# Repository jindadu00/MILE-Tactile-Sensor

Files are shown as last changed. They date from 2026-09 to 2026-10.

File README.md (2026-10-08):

# MILE Fingertip Visuotactile Sensor

CAD files, material references, fabrication instructions, and LED-control firmware for the fingertip visuotactile sensor used in **MILE: A Mechanically Isomorphic Hand Exoskeleton and Visuotactile Robotic Hand for Data Collection in Dexterous Manipulation**.

[MILE project page](https://sites.google.com/view/mile-system) · [Bill of materials](BOM/BOM.xlsx)

## Sensor overview

The module combines a compliant silicone sensing layer, a reflective coating, a transparent acrylic support, internal LED illumination with an ATtiny85-based controller, a miniature RGB camera with a **120° fixed-focus lens**, and printed structural parts. The documented assembly uses **eight LEDs** for red, green, and blue illumination from three directions. The supplied firmware defines **ten color positions** in the order `RRRBBGGGBB`, with the final two blue LEDs optional.

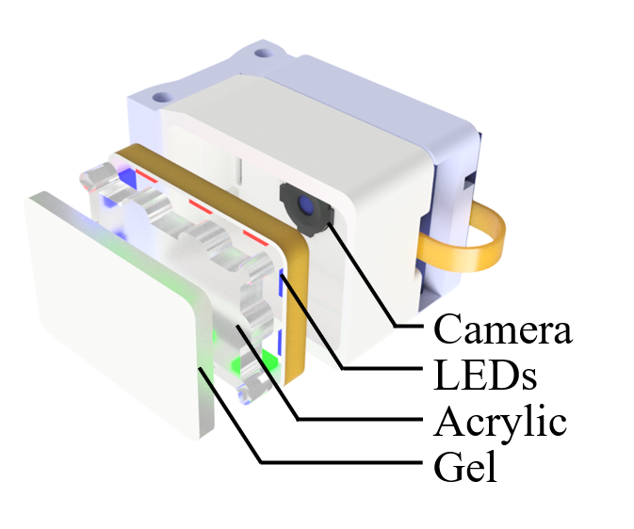
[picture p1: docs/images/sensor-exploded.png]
Exploded view of the sensor, showing the camera, LEDs, acrylic support, and gel layer.


*Sensor exploded view corresponding to Fig. 3(d) of the MILE manuscript.*

## Released files

| File | Description |
| --- | --- |
| [assembly.STEP](CAD/STEP/assembly.STEP) | Sensor assembly |
| [baseCamera.STEP](CAD/STEP/baseCamera.STEP) | Camera-side structural component |
| [baseConnector.STEP](CAD/STEP/baseConnector.STEP) | Connecting structural component |
| [acrylic.STEP](CAD/STEP/acrylic.STEP) | Geometry of the 3 mm transparent acrylic support |
| [acrylic.DXF](CAD/DXF/acrylic.DXF) | Laser-cutting outline for the 3 mm acrylic support |
| [camera.STEP](CAD/STEP/camera.STEP) | Camera geometry reference |
| [GelMode.STEP](CAD/STEP/GelMode.STEP) | Silicone casting mold, printed in PLA |
| [BOM.xlsx](BOM/BOM.xlsx) | Components, consumables, and supplier references |
| [Illumination assembly and wiring](docs/led-wiring.md) | Assembly reference photographs and soldering instructions |
| [MILE_LED.ino](Firmware/MILE_LED/MILE_LED.ino) | ATtiny85 LED-control sketch with the `RRRBBGGGBB` color sequence |
| [Firmware setup](Firmware/README.md) | Upload instructions, pin settings, and brightness configuration |

This release covers mechanical designs, material references, fabrication, hardware assembly, and LED-control firmware.

## Materials and supplier references

Silicone, coatings, adhesives, wires, and printing materials are shared consumables. Links were supplied by the authors; confirm product options before purchase.

| **Component or material** | **Specification / role** | **Supplier reference** |
| --- | --- | --- |
| Silicone elastomer | Smooth-On Solaris; MILE recipe: A:B = **1:2 by mass** | [Listing](https://e.tb.cn/h.8CfLBqZ0Gq6BevB?tk=VI4yTMjDRcV) |
| Mold release agent | Coat the internal casting surfaces | [Listing](https://item.taobao.com/item.htm?id=39270711126) |
| Transparent silicone adhesive | Bond the uncoated gel surface to acrylic | [Listing](https://item.taobao.com/item.htm?id=593987256695) |
| White thermally conductive adhesive | Fix the camera after focusing | [Listing](https://item.taobao.com/item.htm?id=600594258578) |
| Gray silicone coating ink | Request custom **coolgray** | [Listing](https://item.taobao.com/item.htm?id=594951473152) |
| Coating thinner | Compatible thinner from the coating supplier | [Listing](https://item.taobao.com/item.htm?id=594951473152) |
| LED strip | 2.6 mm wide; **8 LEDs in the documented assembly**; firmware defines 10 color positions with the final 2 blue LEDs optional | [Listing](https://item.taobao.com/item.htm?id=570411659913) |
| LED controller | ATtiny85-based controller board | [Listing](https://detail.tmall.com/item.htm?id=654071116354) |
| Camera | **120° fixed-focus module with small board** | [Listing](https://item.taobao.com/item.htm?id=713113178023) |
| 3D printing filament | Bambu PLA Basic| [Listing](https://e.tb.cn/h.8yFoHAKwVr1shmb?tk=97oXTMkPX9c) |

Additional procurement references for C-0030 silicone, silver ink, marker ink, and spray-gun cleaner are retained in `Sheet2` of the spreadsheet. They are not required additions to the recipe below.

## Fabrication and assembly

### 1. Prepare the mold and parts

1. Print [GelMode.STEP](CAD/STEP/GelMode.STEP) in PLA to make the silicone casting mold.
2. Temporarily seal the mold's open bottom with a flat acrylic plate to prevent leakage during casting and curing. The open-bottom design facilitates removal of the cured silicone layer. This sealing plate is separate from the sensor's acrylic support.
3. Apply mold release agent to the internal casting surfaces, following the release agent's instructions.
4. Print `baseCamera` and `baseConnector` in PLA.
5. Cut the sensor support from **3 mm transparent acrylic** using [acrylic.DXF](CAD/DXF/acrylic.DXF). Import the drawing in millimeters without scaling.

### 2. Mix, degas, and cast the silicone

1. Weigh Solaris A and B at **A:B = 1:2 by mass**. For example, combine 10 g of A with 20 g of B.
2. Mix thoroughly with a mixer or manually with a spoon/spatula, incorporating the material along the container walls and bottom.
3. Degas in a vacuum chamber until bubbles introduced during mixing are removed. Leave space for the mixture to expand during degassing.
4. Pour the degassed mixture into the prepared mold, minimizing new bubbles.
5. Leave the filled mold in a **45°C temperature-controlled chamber for 24 h**, following the authors' laboratory fabrication procedure.
6. Demold the transparent silicone layer and check the optical region for bubbles and defects.

**Formulation selection:** Section III-C of the manuscript specifies A:B = 1:2 by mass. Supplementary Section IV-B describes screening ten ratios using compression force-displacement responses and qualitative observations of clarity, recovery, tackiness, and fabrication stability. The selected formulation is a practical compromise for this sensor, rather than a universal optimum.

The [manufacturer's technical bulletin](https://www.smooth-on.com/tb/files/Solaris_TB.pdf) specifies a standard 1:1 formulation. The **1:2 formulation above is the experimentally selected MILE recipe**. The 45°C / 24 h schedule is the laboratory procedure supplied by the authors.

### 3. Apply the reflective coating

1. Weigh gray ink stock and its compatible thinner at **ink:thinner = 1:3 by mass**.
2. Add the curing agent supplied with the ink at the supplier's specified dose, mix thoroughly, then use a spray gun to deposit a thin, uniform film on the contact-facing silicone surface. The curing-agent dose is separate from the ink-to-thinner ratio.
3. Make the coating uniform and opaque. Avoid excessive thickness, which can reduce sensing sensitivity according to the authors' fabrication observations.
4. Allow the coating to dry for approximately **8 h at room temperature**, or accelerate drying with a heat gun. Ensure that the coating is fully dry before assembly.

Leave the opposite gel surface uncoated for bonding to acrylic.

### 4. Assemble illumination, acrylic, and gel

1. Assemble the acrylic support and LED strip according to the exploded view and assembly CAD. The documented assembly uses **eight LEDs**, corresponding to the first eight positions of the firmware sequence `RRRBBGGGBB`. The final two blue LEDs can be omitted from the end of the signal chain. Secure the support in the middle of the sensor structure.
2. Route and solder the LED wires: **red for 5 V**, **black for ground**, and **blue for the control signal**. The camera board supplies shared 5 V and ground to the ATtiny85 board. Upload the [LED-control sketch](Firmware/MILE_LED/MILE_LED.ino) using the [firmware setup instructions](Firmware/README.md), then check the color order and illumination before bonding the gel. See [assembly photographs and soldering instructions](docs/led-wiring.md).
3. Use transparent silicone adhesive to bond the **uncoated side** of the gel to acrylic. Avoid trapped air in the optical interface.
4. Allow approximately **8 h at room temperature** for the bond to cure, following the authors' procedure for the selected adhesive. Check the bond before continuing.

### 5. Install and focus the camera

1. After the gel-to-acrylic bond has cured, insert the camera into the structure's viewing opening.
2. With illumination on and the camera image displayed, adjust focus for the clearest view of the sensing surface at the assembled distance.
3. Fix the camera with thermally conductive adhesive. Keep adhesive away from the lens and optical path, and preserve the focused camera pose during fixation.
4. After fixation, check illumination coverage, image focus, and visible image changes under gentle contact.

## Maintenance

The modular construction allows the gel and camera to be replaced separately. Replace a damaged gel while retaining the camera, or replace and refocus a damaged camera while retaining the gel. During removal, protect the illumination assembly and the gel or camera being retained. The acrylic support can be replaced as needed.

## Citation

Please cite the associated [MILE arXiv preprint](https://arxiv.org/abs/2512.00324). A downloadable BibTeX entry is provided in [citation.bib](citation.bib).

```bibtex
@misc{du2025milemechanicallyisomorphicexoskeleton,
  title         = {MILE: A Mechanically Isomorphic Hand Exoskeleton and Visuotactile Robotic Hand for Data Collection in Dexterous Manipulation},
  author        = {Jinda Du and Jieji Ren and Qiaojun Yu and Ningbin Zhang and
                   Yu Deng and Xingyu Wei and Yufei Liu and Guoying Gu and
                   Xiangyang Zhu},
  year          = {2025},
  eprint        = {2512.00324},
  archivePrefix = {arXiv},
  primaryClass  = {cs.RO},
  url           = {https://arxiv.org/abs/2512.00324}
}
```

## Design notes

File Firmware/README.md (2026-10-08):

# LED-control firmware

[MILE_LED/MILE_LED.ino](MILE_LED/MILE_LED.ino) provides constant RGB illumination using an ATtiny85 board and the [Adafruit NeoPixel library](https://github.com/adafruit/Adafruit_NeoPixel).

## Configuration

| Setting | Default | Description |
| --- | --- | --- |
| `LED_PIN` | `3` | Arduino digital-pin number; P3 / PB3 on the pictured ATtiny85 board |
| `LED_PATTERN` | `"RRRBBGGGBB"` | Color order from the signal-input end of the LED strip |
| `NUMPIXELS` | `10` | Calculated from the pattern length |
| `RED_LEVEL` | `15` | Red channel setting, 0–255 |
| `GREEN_LEVEL` | `15` | Green channel setting, 0–255 |
| `BLUE_LEVEL` | `15` | Blue channel setting, 0–255 |
| Pixel format | `NEO_GRB + NEO_KHZ800` | GRB byte order and 800 kHz signaling, retained from the supplied sketch |

The first eight color positions are `RRRBBGGG`. If the last two blue LEDs are omitted from the physical strip, the same sketch still supplies the correct colors to those first eight LEDs. This applies when LEDs are omitted from the **end of the signal chain**; omitting LEDs at its beginning or middle requires adjusting the pattern.

The brightness defaults are adjustable starting values, not recovered experimental calibration. Tune them with the assembled gel and camera at the intended exposure, checking for clipping and uneven illumination. The optional final two LEDs change the illumination distribution when fitted.

## Upload and check

1. Install Arduino IDE and the board package appropriate for the ATtiny85 controller. Select the actual board and CPU clock configuration. For board support, consult the [ATTinyCore documentation](https://github.com/SpenceKonde/ATTinyCore).
2. Install **Adafruit NeoPixel** through the Arduino Library Manager.
3. Open `MILE_LED/MILE_LED.ino`. Keep the sketch inside the folder named `MILE_LED`.
4. Match `LED_PIN` to the blue signal wire's board terminal. The supplied assembly uses P3 / PB3. Check the strip's input direction and pixel format.
5. Compile and upload using the selected board's supported upload method. On [Digispark-style boards](https://github.com/ArminJo/DigistumpArduino#pin-layout), P3 also carries USB data; disconnect the LED signal wire during USB programming and reconnect it afterward. Restore the [shared camera-board 5 V and ground connections](../docs/led-wiring.md) for operation.
6. Verify the color order before final assembly. Temporarily setting `LED_PATTERN` to `"R......."` lights only index 0 on an eight-position strip. `"G......."` and `"B......."` allow checking the other color channels; restore `"RRRBBGGGBB"` afterward.
7. Adjust `RED_LEVEL`, `GREEN_LEVEL`, and `BLUE_LEVEL` as needed, then check the assembled camera image.

The sketch sets all pixel colors in `setup()` and transmits one frame. `loop()` is empty because the LEDs retain the last transmitted colors for constant illumination.

## License

The sketch is adapted from the NeoPixel Ring simple example by Shae Erisson (2013) and retains its GPLv3 license notice. [MILE_LED/LICENSE.txt](MILE_LED/LICENSE.txt) contains the license text for this sketch.

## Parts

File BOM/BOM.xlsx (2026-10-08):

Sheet: Sheet1
Component | Specification | Purchase Link
Silicone elastomer | Solaris; A:B = 1:2 by mass (MILE manuscript III-C) | https://e.tb.cn/h.8CfLBqZ0Gq6BevB?tk=VI4yTMjDRcV
Silicone adhesive | Transparent silicone adhesive; gel-to-acrylic bond | https://item.taobao.com/item.htm?id=593987256695
Miniature camera module | 120° fixed-focus module with small board | https://item.taobao.com/item.htm?id=713113178023
Microcontroller board | ATtiny85-based LED controller board | https://detail.tmall.com/item.htm?id=654071116354
LEDs (strip segment) | 2.6 mm RGB strip; 8 LEDs in assembly; 10 firmware positions, final 2 blue optional | https://item.taobao.com/item.htm?id=570411659913
3D printing filament | Bambu PLA Basic; for the silicone casting mold and sensor structural parts | https://e.tb.cn/h.8yFoHAKwVr1shmb?tk=97oXTMkPX9c
Mold release agent | Apply to internal surfaces of gel casting mold | https://item.taobao.com/item.htm?id=39270711126
Gray silicone coating ink | Custom coolgray; dry at room temperature ~8 h; a heat gun can accelerate drying | https://item.taobao.com/item.htm?id=594951473152
Coating thinner | Compatible thinner; ink:thinner = 1:3 by mass | https://item.taobao.com/item.htm?id=594951473152
Thermally conductive adhesive | White adhesive; fix camera after focus adjustment | https://item.taobao.com/item.htm?id=600594258578

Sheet: Sheet2
Reference item | Specification / use | Purchase Link | Selection note
C-0030 silicone | Supplier notes: A 250 g + B 250 g | https://item.taobao.com/item.htm?id=668500306966 | Reference only; not Solaris recipe
Spray-gun cleaner | T-03 cleaner | https://item.taobao.com/item.htm?id=827040574354 | Equipment cleaning consumable
Marker ink | Black fluorescent tactile marker ink | https://item.taobao.com/item.htm?id=599683958497 | Reference only; not in described recipe
Silver ink | Silver coating ink | https://item.taobao.com/item.htm?id=601283906543 | Reference only; gray ink used in described recipe

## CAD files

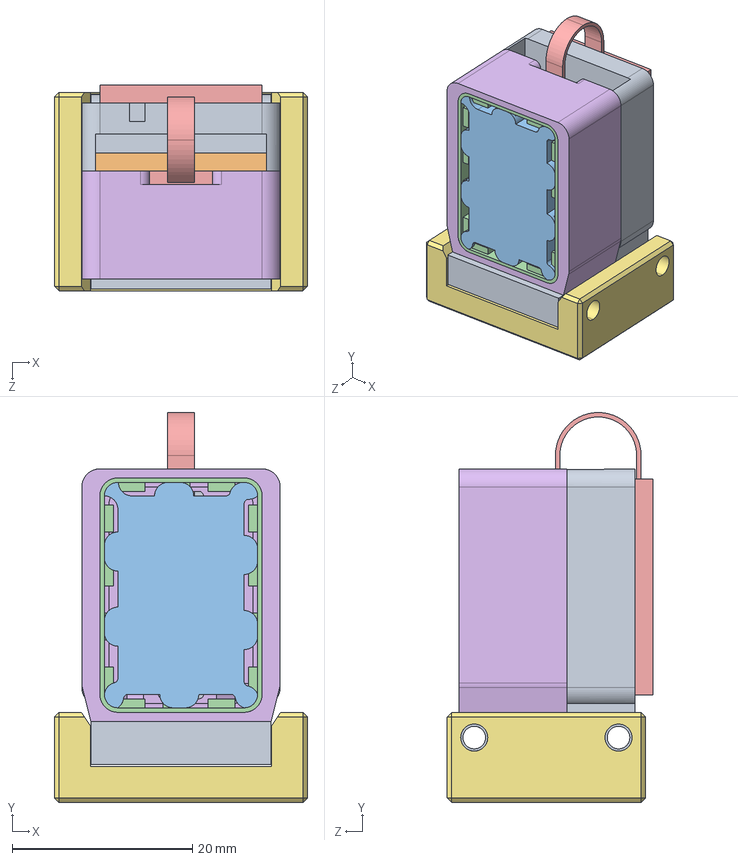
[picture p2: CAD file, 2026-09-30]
CAD/STEP/assembly.STEP
28.1 x 43.3 x 22.8 mm
baseConnector_v0.2
ATtiny
acrylic
LED
microCamera
base
fingertipConnector

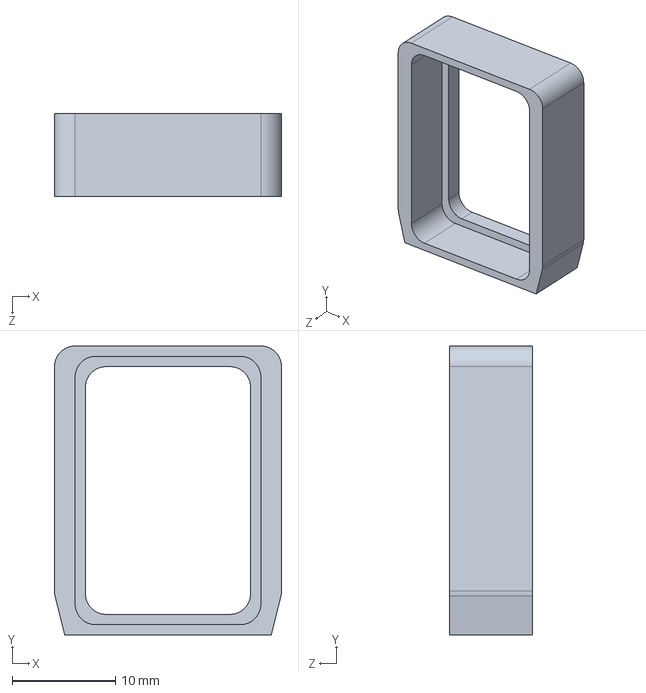
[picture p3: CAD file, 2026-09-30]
CAD/STEP/GelMode.STEP
22.0 x 28.0 x 8.00 mm

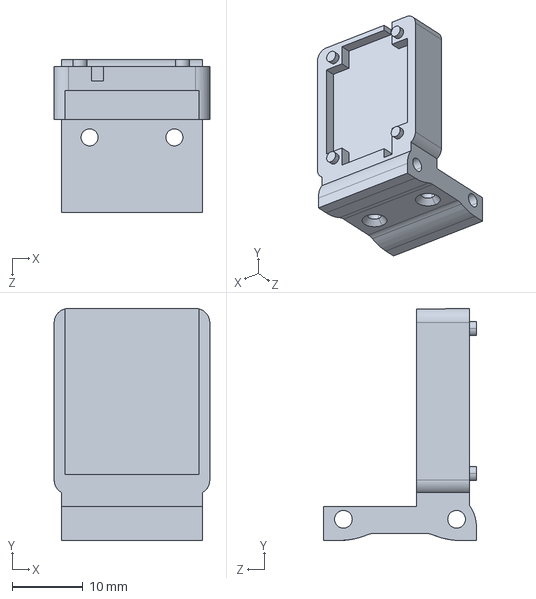
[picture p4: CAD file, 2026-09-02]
CAD/STEP/baseConnector.STEP
22.0 x 32.8 x 21.6 mm

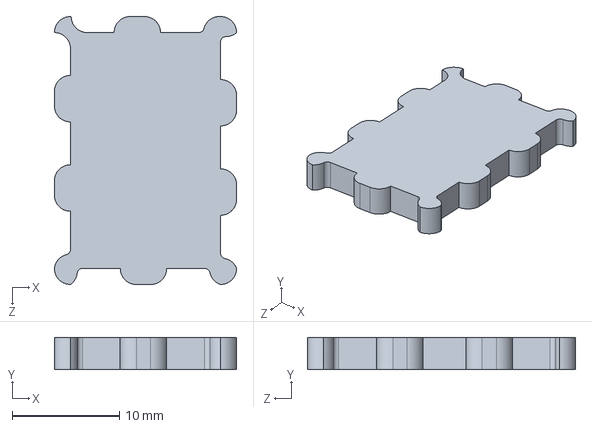
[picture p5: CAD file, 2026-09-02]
CAD/STEP/acrylic.STEP
17.0 x 3.00 x 25.0 mm

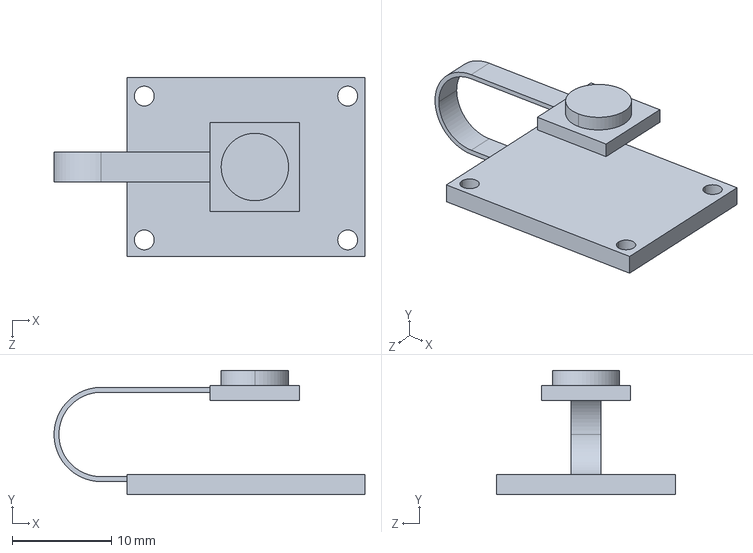
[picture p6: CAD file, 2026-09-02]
CAD/STEP/camera.STEP
31.4 x 12.5 x 18.0 mm

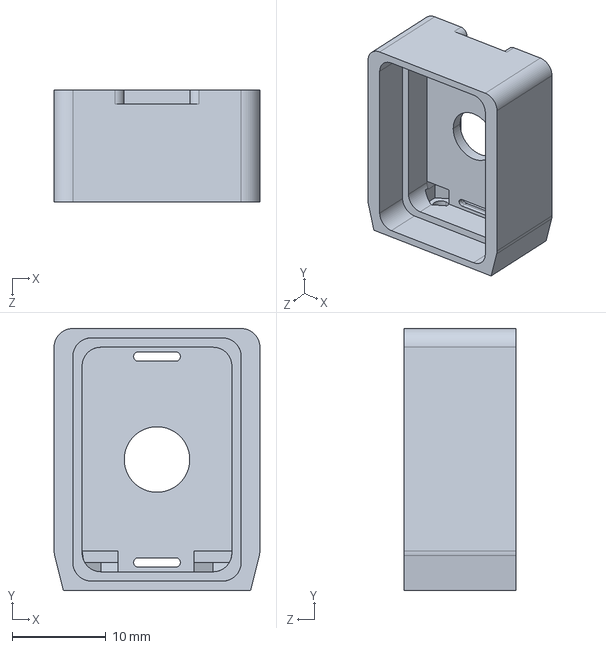
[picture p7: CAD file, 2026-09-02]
CAD/STEP/baseCamera.STEP
22.0 x 28.0 x 12.0 mm

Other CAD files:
CAD/DXF/acrylic.DXF

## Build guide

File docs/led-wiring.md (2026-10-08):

# Illumination assembly and wiring

The photographs below show the sensor's LED strip seated inside the printed housing, the ATtiny85 controller board, and the camera board. The documented assembly uses **eight LEDs** for red, green, and blue illumination from three directions. The released firmware defines ten color positions, `RRRBBGGGBB`, with the final two blue LEDs optional. The camera uses a **120° fixed-focus lens**. The camera board provides a shared **5 V supply**, and the ATtiny85 board controls the LED strip.

## Assembly photographs

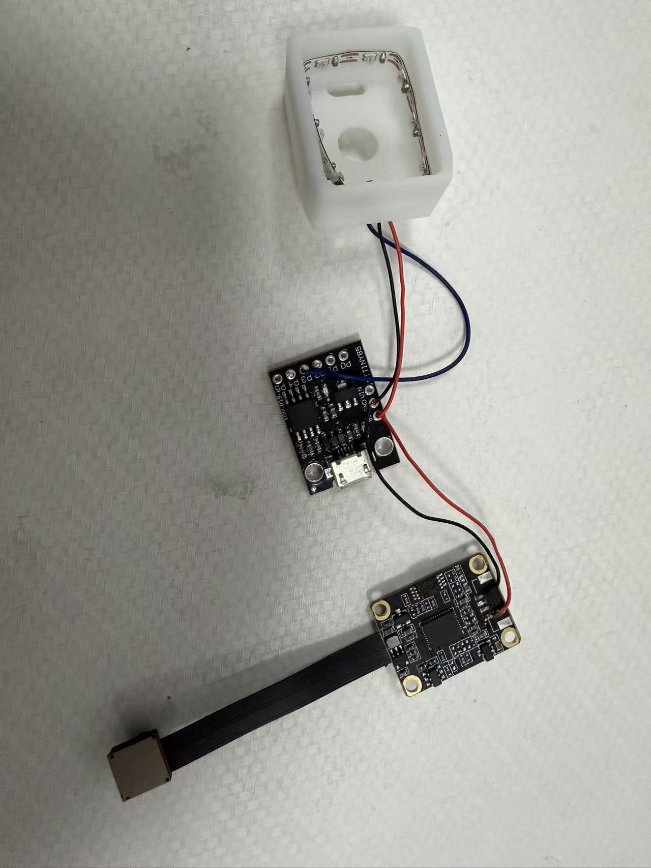
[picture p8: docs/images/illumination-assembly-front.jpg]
LED strip inside the sensor housing, controller board front, and camera board connected by wires.


*Front view of the illumination assembly and connected boards. The LED strip follows the inner perimeter of the housing, and the wires leave through the housing opening.*

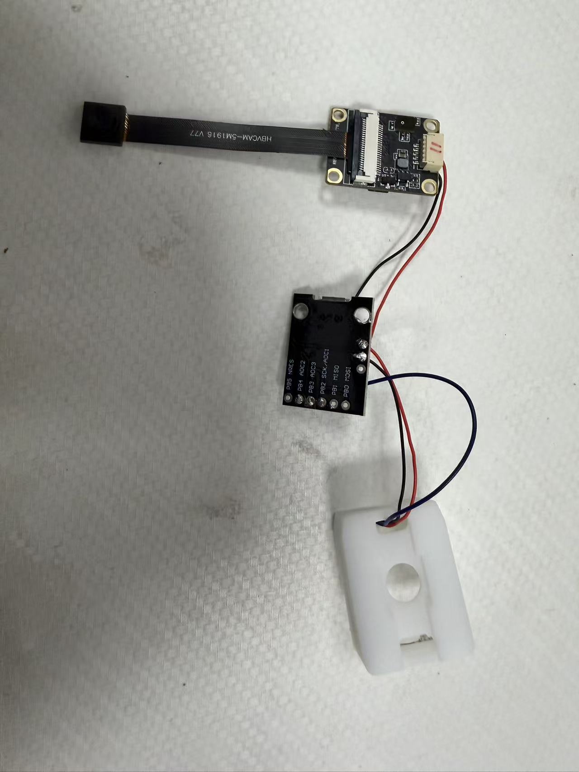
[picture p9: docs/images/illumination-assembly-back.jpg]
Reverse view of the controller board with printed pin labels, the camera board, and the sensor housing.


## Soldering and assembly

1. Position the LED strip along the inner perimeter of the housing as shown in the photographs and assembly CAD. The documented eight-LED assembly uses the first eight positions, `RRRBBGGG`; two additional blue LEDs can occupy the end of the signal chain. Follow the strip's permitted bend and cut locations.
2. Identify the **5 V**, **ground**, and **signal-input** pads on the LED strip and the corresponding connections on the ATtiny85 board. Follow the terminal labels and the strip's input direction.
3. Route flexible wires through the housing opening. Leave sufficient length for assembly and servicing without pulling on the solder joints.
4. Connect the LED strip to the ATtiny85 board using **red for 5 V**, **black for ground**, and **blue for the LED control signal**. Connect the camera board to the ATtiny85 board using **red for 5 V** and **black for ground**, so the illumination assembly shares the camera board's 5 V supply. Keep solder joints compact and avoid bridges between adjacent pads.
5. Check continuity and ensure that supply and ground are not shorted before powering the assembly. Insulate exposed connections where needed and keep wires clear of the camera opening and acrylic seating surfaces.
6. Upload the [LED-control sketch](../Firmware/MILE_LED/MILE_LED.ino), power the camera board, and check the color order and illumination before fixing the acrylic support and bonding the gel. See [firmware setup](../Firmware/README.md).

## Connection roles

| Connection | Wire color | Function |
| --- | --- | --- |
| Camera board → ATtiny85 board | Red | Shared 5 V supply |
| Camera board → ATtiny85 board | Black | Common ground |
| ATtiny85 board → LED strip | Red | LED-strip 5 V supply |
| ATtiny85 board → LED strip | Black | LED-strip ground |
| ATtiny85 board → LED strip | Blue | LED control signal; default firmware output is digital pin 3 (P3 / PB3 on the pictured board) |

The camera board, ATtiny85 board, and LED strip share the same ground. The blue wire carries the control signal from the ATtiny85 board to the LED strip's signal input. `LED_PIN` is an Arduino digital-pin number; match it to the board's pin mapping and the actual signal-wire connection.

## LED color order

Count LEDs from the signal-input end, starting at index 0:

| LED index | Color |
| --- | --- |
| 0–2 | Red |
| 3–4 | Blue |
| 5–7 | Green |
| 8–9 | Blue (optional final LEDs) |

If the final two LEDs are physically absent, the first eight retain the same colors. Removing LEDs from the beginning or middle changes the index-to-position mapping. Brightness is configurable in the sketch; check the assembled camera image after changing the illumination.

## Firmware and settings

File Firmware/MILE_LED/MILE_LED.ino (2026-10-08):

// SPDX-License-Identifier: GPL-3.0-only
// Based on NeoPixel Ring simple sketch (c) 2013 Shae Erisson.
// Adapted for constant RGB illumination in the MILE fingertip sensor.

#include <Adafruit_NeoPixel.h>
#ifdef __AVR__
#include <avr/power.h>
#endif

// Arduino digital-pin number, not the ATtiny85 package-pin number.
// Default for the pictured ATtiny85 board: P3 / PB3.
// Match this value to the signal-wire connection and selected board core.
const uint8_t LED_PIN = 3;

// Pixel indices start at the first LED connected to the signal-input end.
// Red, red, red, blue, blue, green, green, green, blue, blue.
// If only the first eight LEDs are physically present, they keep the same
// colors (RRRBBGGG); the final two blue positions have no attached LEDs.
// This assumes LEDs are omitted only from the end of the signal chain.
const char LED_PATTERN[] = "RRRBBGGGBB";
const uint16_t NUMPIXELS = sizeof(LED_PATTERN) - 1;

// Adjustable starting values, not recovered experimental calibration.
// Tune each channel with the assembled camera, exposure, and gel.
const uint8_t RED_LEVEL = 15;
const uint8_t GREEN_LEVEL = 15;
const uint8_t BLUE_LEVEL = 15;

// Retained from the supplied code; verify the actual strip format.
Adafruit_NeoPixel pixels(NUMPIXELS, LED_PIN, NEO_GRB + NEO_KHZ800);

void setup() {
  // Preserve the supplied Adafruit example's 16 MHz ATtiny85 setup.
#if defined(__AVR_ATtiny85__) && (F_CPU == 16000000)
  clock_prescale_set(clock_div_1);
#endif

  pixels.begin();
  pixels.clear();
  for (uint16_t i = 0; i < NUMPIXELS; ++i) {
    switch (LED_PATTERN[i]) {
      case 'R': pixels.setPixelColor(i, RED_LEVEL, 0, 0); break;
      case 'G': pixels.setPixelColor(i, 0, GREEN_LEVEL, 0); break;
      case 'B': pixels.setPixelColor(i, 0, 0, BLUE_LEVEL); break;
    }
  }
  pixels.show();
}

void loop() {
  // Constant illumination: pixels retain the last transmitted colors.
}

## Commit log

2026-09-02 step init
    [acrylic.STEP, assembly.STEP, baseCamera.STEP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]
2026-09-02 Create README.md for MILE Visuotactile Sensor
    Added a README file with project details and resources.
2026-09-02 BOM and instruction
    [BOM.xlsx]
2026-09-30 update v1
    [BOM.xlsx, GelMode.STEP, acrylic.DXF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]
2026-10-08 Add LED firmware
    [BOM.xlsx]
